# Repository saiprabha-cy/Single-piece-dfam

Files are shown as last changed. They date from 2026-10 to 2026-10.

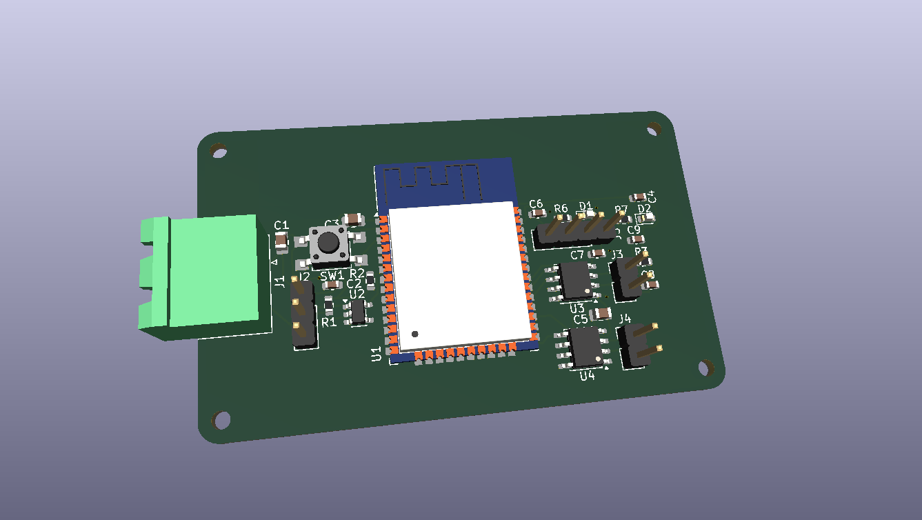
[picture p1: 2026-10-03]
04_kicad_board/sensor_board/sensor_board/sensor_board.png

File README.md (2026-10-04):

# Single-Piece DfAM Redesign of a Liquid Rocket Injector/Nozzle Assembly

A capstone project applying **Design for Additive Manufacturing (DfAM)**
principles to a small liquid rocket engine injector/nozzle assembly —
exploring how a traditionally multi-part, bolted engine assembly can be
redesigned as a single consolidated 3D-printed part.

## Motivation

Several modern small-launch-vehicle companies have moved toward 3D-printing
entire rocket engines as a single piece, eliminating the joints, fasteners,
and assembly steps of traditionally machined multi-part engines. This
project applies that same design philosophy at a smaller, student-accessible
scale: take a conventionally-designed multi-part injector/nozzle assembly,
redesign it as one consolidated additively-manufactured part, and validate
the redesign with both hand calculations and simulation.

## Project Stages

| Stage | Folder | Status |
|---|---|---|
| 1. Propulsion calculations | `01_calculations/` | ✅ Complete |
| 2. Baseline multi-part CAD | `02_cad/baseline_multipart/` | ✅ Complete |
| 3. Single-piece DfAM redesign | `02_cad/dfam_redesign/` | ✅ Complete |
| 4. Structural/thermal validation | `03_simulation/` | ✅ Structural complete; thermal documented as a known limitation |
| 5. Sensor/telemetry board | `04_kicad_board/` | ✅ Complete (0 DRC errors) |
| 6. Print-readiness analysis | `05_print_readiness/` | 🔜 Scoped as future work (see below) |
| 7. Final report | `06_report/` | ✅ Complete |

## Design Case (Assumed, Representative Values)

This project uses **representative values** for a generic small LOX/Kerosene
test-case engine, not any specific company's proprietary specifications.

- Target thrust: 3,000 N
- Chamber pressure: 20 bar
- Propellants: LOX / Kerosene (RP-1)
- Assumed sea-level Isp: 290 s

## Key Results

| Metric | Baseline (multi-part) | Redesign (single-piece) |
|---|---|---|
| Part count | 3 | 1 |
| Fastener interfaces | 2 (1 bolted, 1 rigid-joint only) | 0 |
| Mounting holes | 8 | 0 |
| Cooling provisions | None | 6 integrated channels |
| Structural safety factor (20 bar) | — | 6.24 (Ti-6Al-4V, SimScale) |

## Tools Used

- **Python** (SciPy) — propulsion calculations
- **Autodesk Fusion 360** (Personal Use license) — CAD modeling + built-in simulation
- **SimScale** — structural/thermal validation
- **KiCad** — sensor/telemetry PCB design

### Future Extensions
- **PrusaSlicer / Cura** — print-readiness and support-structure analysis
  (scoped as future work; see `05_print_readiness/`)
- Coolant inlet/outlet port routing on the DfAM redesign
- Full channel count (6 → 24) for production-representative coverage
- Chamber L* correction (increase straight-section length for realistic
  combustion residence time)

## Known Limitations

- **Chamber L\*** (characteristic length) is 263mm against a typical
  800-1500mm range for LOX/Kerosene engines — the as-modeled chamber is
  shorter than standard practice would recommend. This is a known,
  documented simplification; it does not affect the validity of the
  single-piece consolidation comparison, which is geometry-independent of
  chamber length. See `01_calculations/results/design_targets.json`.
- **Thermal simulation** was attempted in SimScale but diverged (likely due
  to an incomplete fluid-flow boundary definition in the initial CHT setup).
  Due to free-tier compute limits, a corrected re-run was not completed.
  The Stage 1 hand-calculated estimate (19.2 MW/m², target wall temp 800K)
  is retained as the primary thermal reference. See
  `03_simulation/validation_comparison.md`.
- **Cooling channel count** was reduced from a production-representative
  24 channels to 6, to keep the modeling scope achievable within the
  project timeline.
- **Print-readiness analysis** (slicer-based orientation/support check) was
  not completed; see Future Extensions above.

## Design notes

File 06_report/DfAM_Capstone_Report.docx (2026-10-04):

Single-Piece DfAM Redesign of a Liquid Rocket Injector/Nozzle Assembly

A Design-for-Additive-Manufacturing case study: propulsion calculations, baseline CAD, single-piece redesign, structural validation, and instrumentation design

# 1. Motivation

Several modern small-launch-vehicle companies have moved toward 3D-printing entire rocket engines as a single piece, eliminating the joints, fasteners, and assembly steps inherent to traditionally machined multi-part engines. This project applies that same design philosophy at a smaller, student-accessible scale: a conventionally-designed multi-part injector/nozzle assembly is redesigned as one consolidated additively-manufactured part, and the redesign is validated using hand calculations and simulation.

The project uses representative values for a generic small LOX/Kerosene test-case engine throughout — not any specific company's proprietary specifications.

# 2. Design Targets (Propulsion Calculations)

A Python script (SciPy) was used to derive design targets from a set of assumed operating parameters, representative of a small liquid engine test case.

## 2.1 Assumed Inputs

Parameter | Value
Target thrust | 3,000 N
Chamber pressure | 20 bar (2 MPa)
Propellants | LOX / Kerosene (RP-1)
Assumed sea-level Isp | 290 s
Oxidizer:fuel ratio | 2.5
Characteristic velocity (c*) | 1,750 m/s

## 2.2 Calculated Design Targets

Output | Value
Total propellant mass flow | 1.055 kg/s (0.753 ox + 0.301 fuel)
Injector pressure drop | 3.5 bar (17.5% of chamber pressure)
Oxidizer orifices | 49 × 1.0 mm
Fuel orifices | 24 × 1.0 mm
Throat diameter | 34.28 mm
Exit diameter | 64.97 mm
Exit Mach number | 2.54
Area ratio (Ae/At) | 3.59
Estimated heat flux (throat) | 19.2 MW/m²

## 2.3 Chamber Geometry Check

A characteristic-length (L*) and contraction-ratio check was run against the as-modeled baseline chamber dimensions (Ø55mm bore, 90mm straight length). This returned L* ≈ 263mm, against a typical LOX/Kerosene design range of 800–1500mm. This indicates the chamber, as modeled, is shorter than standard practice would recommend for complete combustion residence time. This is documented as a known limitation; it does not affect the validity of the single-piece consolidation comparison, which is geometry-independent of chamber length.

# 3. Baseline Design (Multi-Part)

The baseline assembly was modeled in Autodesk Fusion 360 (Personal Use license) as three separate components, representative of a traditionally-machined engine assembly:

- Injector plate — Ø70mm disk, 10mm thick, with 73 injector holes (49 oxidizer + 24 fuel) across 5 concentric rings (Ø12/18/24/30/36mm), plus an Ø82mm mounting flange with 8 ×4.5mm clearance holes on a Ø76mm bolt circle
- Combustion chamber — Ø55mm ID, Ø65mm OD, 90mm straight length, 5mm wall
- Nozzle — converging-diverging profile, Ø55mm inlet, Ø34.28mm throat, Ø64.97mm exit, 70mm axial length

The three components were assembled using two rigid joints (injector-to-chamber, chamber-to-nozzle). Only the injector-to-chamber interface includes a bolted flange (8 × M4 clearance holes); the chamber-to-nozzle interface is a positional joint only, without modeled fasteners — noted here as an acknowledged simplification of the baseline.

# 4. Single-Piece DfAM Redesign

The redesign consolidates all three baseline components into a single revolved solid body, modeled directly from the same throat/exit/injector dimensions as the baseline, ensuring a fair comparison.

## 4.1 Design Features

- One continuous revolved body from injector face through chamber, throat, and nozzle exit — no seams, flanges, or fasteners
- Same 73-hole injector pattern (49 oxidizer + 24 fuel), cut into a solid 10mm end cap
- 6 integrated cooling channels (1.5mm liner + 3mm channel height + 2.5mm outer skin), left open at both ends to allow powder removal in a metal powder-bed process and to double as coolant ports
- 1mm fillets at the two internal direction-change corners (chamber-to-throat, throat-to-nozzle) to reduce stress concentration

## 4.2 Part-Count Comparison

Metric | Baseline (multi-part) | Redesign (single-piece)
Part count | 3 | 1
Fastener interfaces | 2 (1 bolted, 1 joint-only) | 0
Mounting holes | 8 | 0
Cooling provisions | None | 6 integrated channels

Note: the cooling channel count (6) was reduced from a production-representative value (e.g. 24) to keep the modeling scope achievable within the project timeline; this is noted as a deliberate simplification.

# 5. Structural & Thermal Validation (SimScale)

## 5.1 Structural Simulation

A static structural simulation was run on the single-piece redesign under a 20 bar (2 MPa) internal pressure load, with the material assigned as Ti-6Al-4V (yield strength ≈ 880 MPa).

Result | Value
Maximum von Mises stress | 141 MPa
Material yield strength (Ti-6Al-4V) | 880 MPa
Safety factor | 6.24

A safety factor of 6.24 indicates the 7mm wall thickness is structurally conservative for the applied pressure load — comfortably exceeding typical aerospace practice (1.5–2.0×). This suggests a future iteration could explore wall-thickness reduction to trade some margin for mass savings.

## 5.2 Thermal Simulation — Documented Limitation

A steady-state thermal simulation was attempted to validate the Stage 1 hand-calculated heat flux estimate (19.2 MW/m², target wall temperature 800K). The initial setup (Conjugate Heat Transfer analysis) produced non-physical results (solver divergence, reporting temperatures from −1832K to 7.99×10⁵K), most likely due to an incomplete fluid-flow boundary definition inherent to the CHT analysis type — a simpler steady-state conduction analysis would have been the more appropriate choice for the boundary conditions defined.

Due to free-tier compute limits on the simulation platform, a corrected re-run was not completed within the project timeline. The Stage 1 first-order estimate is retained as the primary thermal reference for this project. This is reported transparently as a limitation rather than omitted, consistent with the project's overall approach of validating claims and documenting gaps honestly.

# 6. Sensor & Telemetry Board (KiCad)

A sensor/telemetry PCB was designed in KiCad to represent how the redesigned part could be instrumented during a hypothetical static test — directly applying an electronics/embedded-systems background to a propulsion hardware context.

## 6.1 Board Features

- ESP32 microcontroller module for sensor readout and data logging
- Chamber pressure sensor input (analog, with RC low-pass filtering)
- Two thermocouple amplifier inputs (SPI) for throat and injector temperature monitoring
- Onboard voltage regulation (barrel/terminal block input → 3.3V logic rail)
- Reset button, status LEDs, 4-corner mounting holes

The board passed design rule checks (DRC) with 0 errors. Schematic, PCB layout, Gerber/drill files, bill of materials, and a 3D render are included in the project repository.

# 7. Known Limitations & Future Work

- Chamber L* (263mm vs. a typical 800–1500mm range) — the as-modeled chamber is shorter than standard LOX/Kerosene practice would recommend; does not affect the validity of the part-count/consolidation comparison
- Thermal simulation incomplete — documented above; a corrected steady-state conduction run is the logical next step
- Cooling channel count reduced to 6 from a production-representative value for modeling-scope reasons
- Coolant inlet/outlet port routing was not modeled
- Print-readiness analysis (slicer-based orientation and support-structure check) was scoped as future work. The part would realistically be manufactured via metal powder-bed fusion rather than FDM; a slicer tool approximates general printability concepts (overhangs, orientation) but does not simulate the actual metal additive manufacturing process

# 8. Conclusion

This project demonstrates the practical reasoning behind single-piece additive manufacturing for rocket engine hardware: a 3-part, 8-fastener baseline assembly was redesigned as a single consolidated body with zero fasteners and integrated cooling — while remaining dimensionally consistent with hand-calculated propulsion design targets and passing a structural validation check with significant margin (SF = 6.24). Equally important, every limitation encountered along the way — the short chamber L*, the diverged thermal simulation, the reduced channel count — was investigated, understood, and documented rather than hidden, reflecting an engineering approach grounded in validating claims rather than assuming them.

Tools used: Python (SciPy) for propulsion calculations; Autodesk Fusion 360 for CAD modeling and built-in simulation; SimScale for structural and thermal validation; and KiCad for sensor/telemetry PCB design.

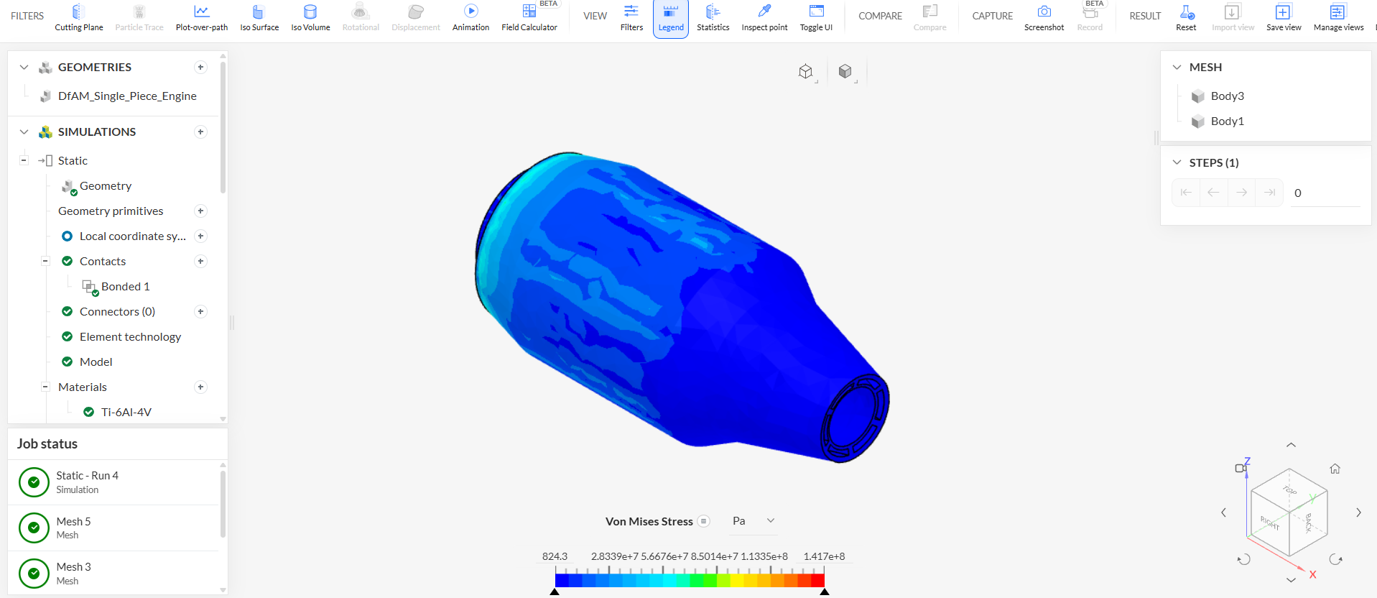
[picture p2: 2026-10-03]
03_simulation/exports/structural_stress_contour.png

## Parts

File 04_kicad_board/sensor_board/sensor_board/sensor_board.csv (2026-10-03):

Id | Designator | Footprint | Quantity | Designation | Supplier and ref
1 | C1 | C_0805_2012Metric | 1 | 10 µF, 10 V
2 | C2 | C_0603_1608Metric | 1 | 100 nF, 10 V
3 | C3 | C_0805_2012Metric | 1 | 10 µF, 6.3 V
4 | C4, C6 | C_0603_1608Metric | 2 | 100 nF
5 | C5 | C_0805_2012Metric | 1 | 10 µF
6 | C7, C8, C9 | C_0603_1608Metric | 3 | 100nF
7 | D1, D2 | LED_0603_1608Metric | 2 | LED
8 | J1 | PhoenixContact_MSTBA_2,5_2-G_1x02_P5.00mm_Horizontal | 1 | POWER IN
9 | J2 | PinHeader_1x03_P2.54mm_Vertical | 1 | PRESSURE
10 | J3 | PinHeader_1x02_P2.54mm_Vertical | 1 | THERMOCOUPLE 1
11 | J4 | PinHeader_1x02_P2.54mm_Vertical | 1 | THERMOCOUPLE 2
12 | J5 | PinHeader_1x04_P2.54mm_Vertical | 1 | UART
13 | R1, R6, R7 | R_0603_1608Metric | 3 | 1k
14 | R2 | R_0603_1608Metric | 1 | 10k
15 | R3 | R_0603_1608Metric | 1 | 20k
16 | SW1 | SW_SPST_TL3305A | 1 | RESET
17 | U1 | ESP32-WROOM-32 | 1 | ESP32-WROOM-32E
18 | U2 | SOT-23-5 | 1 | AP2112K-3.3
19 | U3, U4 | SOIC-8_3.9x4.9mm_P1.27mm | 2 | MAX31855EASA

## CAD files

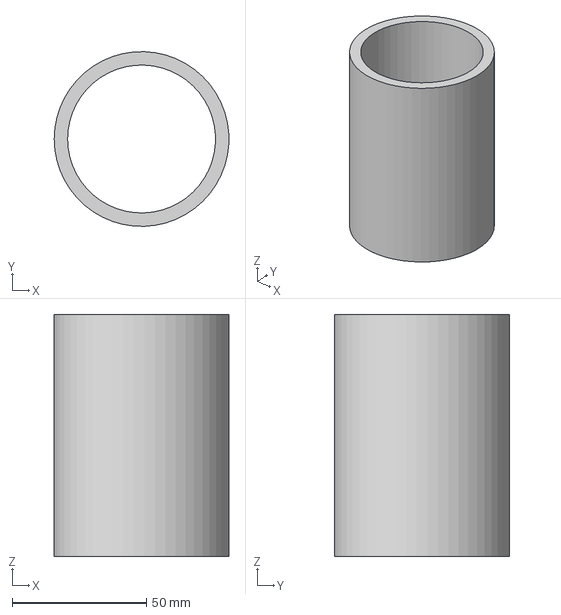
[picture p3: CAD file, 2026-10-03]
02_cad/baseline_multipart/STEP_Exports/Combustion_Chamber.step
64.9 x 65.0 x 90.0 mm

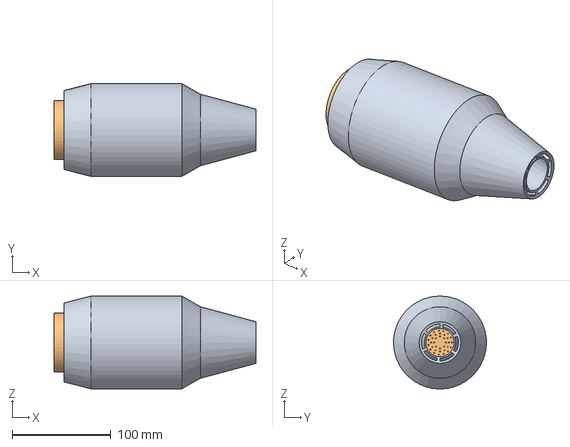
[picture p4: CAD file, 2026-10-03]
02_cad/dfam_redesign/STEP_Exports/DfAM_Single_Piece_Engine.step
204.3 x 94.0 x 93.9 mm

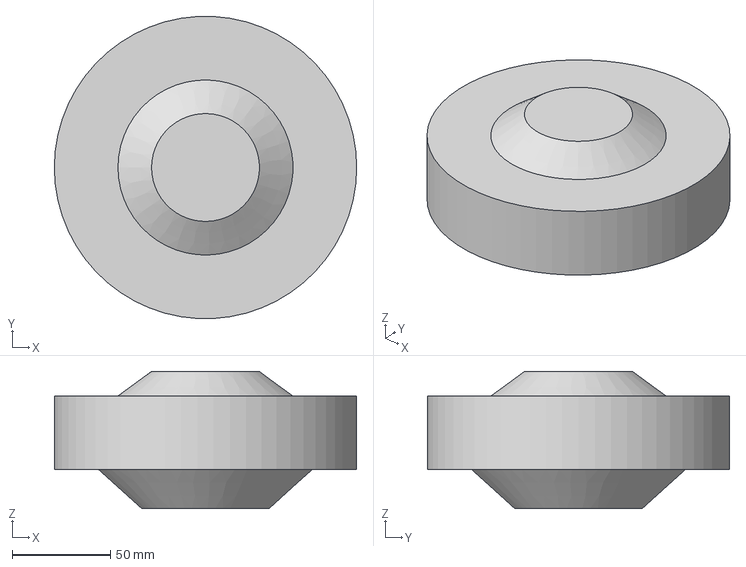
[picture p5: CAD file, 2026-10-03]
02_cad/baseline_multipart/STEP_Exports/Nozzle.step
154.2 x 154.0 x 70.0 mm

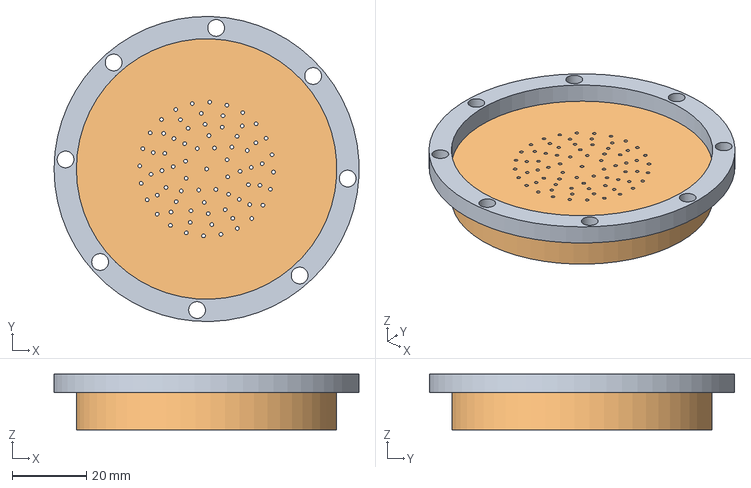
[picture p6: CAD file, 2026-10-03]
02_cad/baseline_multipart/STEP_Exports/Injector_Plate.step
81.9 x 82.0 x 15.0 mm

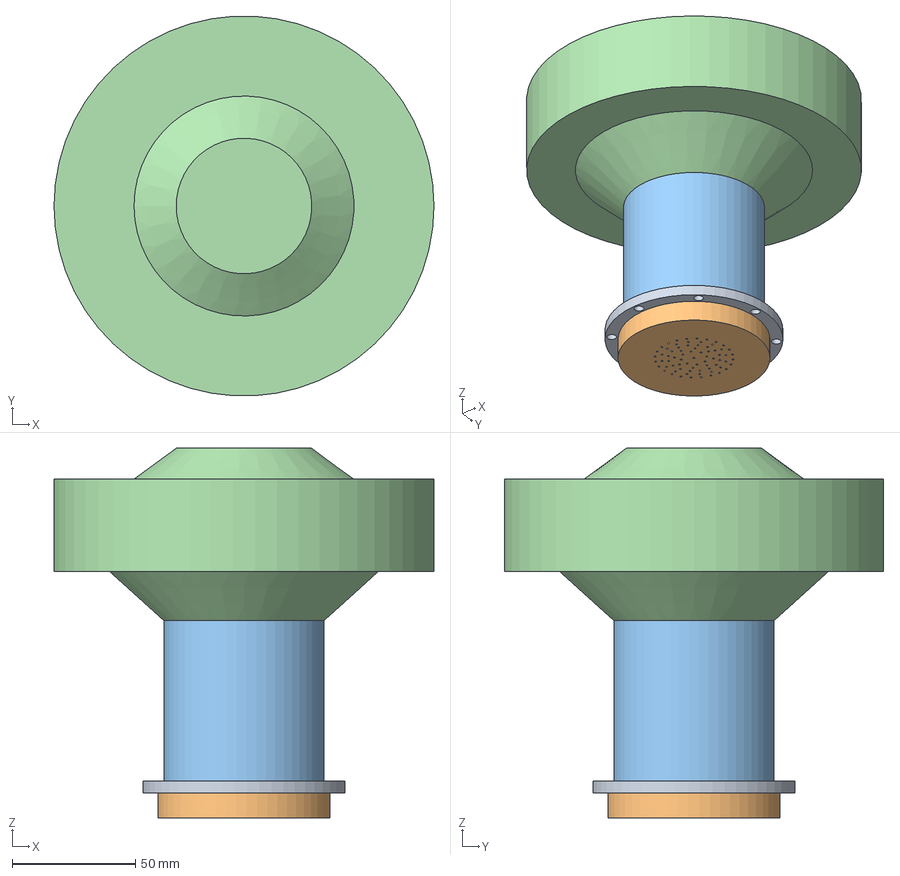
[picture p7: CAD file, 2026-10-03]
02_cad/baseline_multipart/STEP_Exports/Baseline_Injector_Plate.step
154.2 x 154.0 x 150.0 mm

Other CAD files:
05_print_readiness/DfAM_Single_Piece_Engine.stl

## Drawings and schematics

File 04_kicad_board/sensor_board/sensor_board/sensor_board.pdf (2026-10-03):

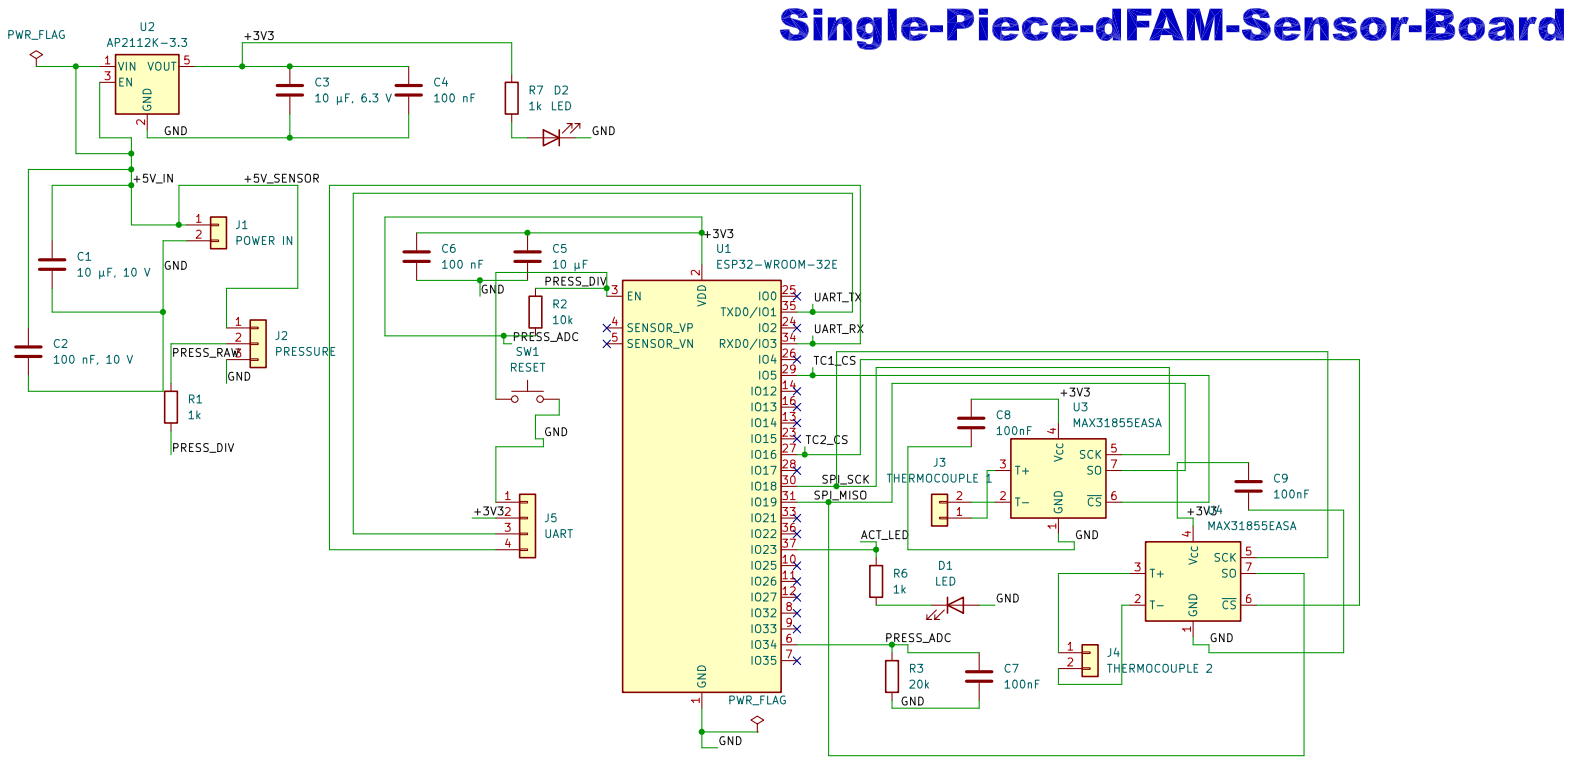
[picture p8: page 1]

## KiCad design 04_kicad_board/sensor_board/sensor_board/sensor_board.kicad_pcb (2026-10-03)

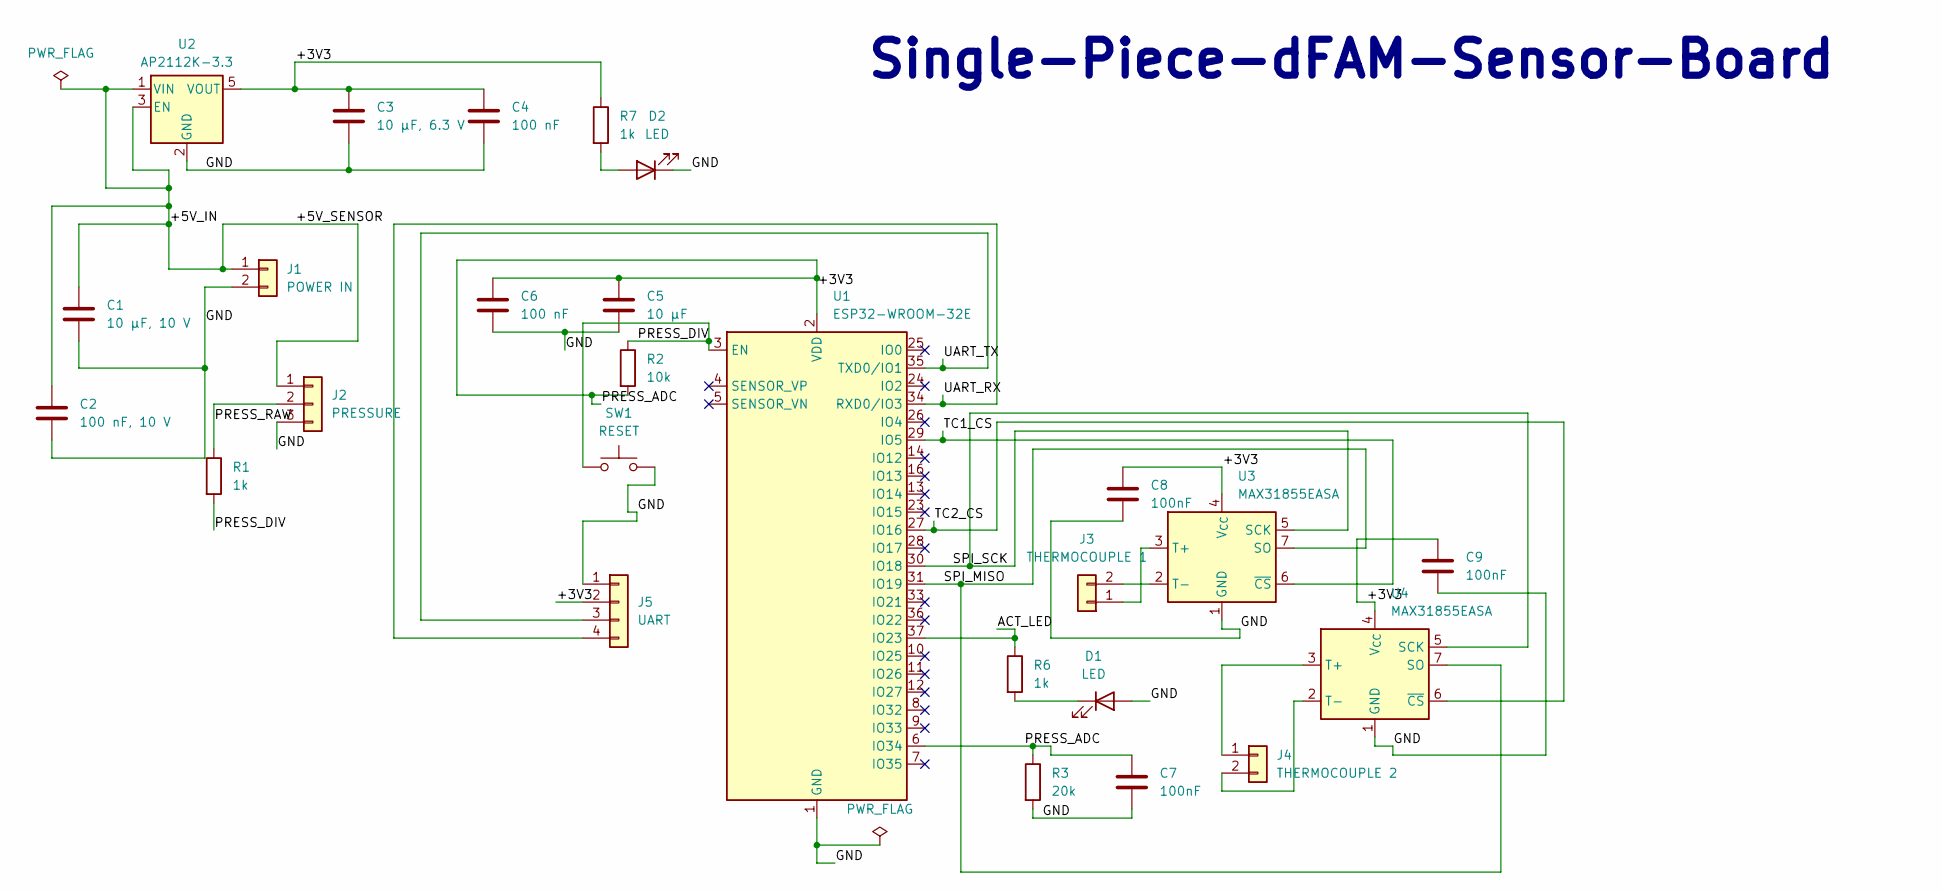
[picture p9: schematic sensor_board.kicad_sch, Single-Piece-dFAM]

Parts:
C1: 10 µF, 10 V; C_0805_2012Metric
C2: 100 nF, 10 V; C_0603_1608Metric
C3: 10 µF, 6.3 V; C_0805_2012Metric
C4, C6: 100 nF; C_0603_1608Metric
C5: 10 µF; C_0805_2012Metric
C7, C8, C9: 100nF; C_0603_1608Metric
D1, D2: LED; LED_0603_1608Metric
J1: POWER IN; PhoenixContact_MSTBA_2,5_2-G_1x02_P5.00mm_Horizontal
J2: PRESSURE; PinHeader_1x03_P2.54mm_Vertical
J3: THERMOCOUPLE 1; PinHeader_1x02_P2.54mm_Vertical
J4: THERMOCOUPLE 2; PinHeader_1x02_P2.54mm_Vertical
J5: UART; PinHeader_1x04_P2.54mm_Vertical
R1, R6, R7: 1k; R_0603_1608Metric
R2: 10k; R_0603_1608Metric
R3: 20k; R_0603_1608Metric
SW1: RESET; SW_SPST_TL3305A
U1: ESP32-WROOM-32E; ESP32-WROOM-32
U2: AP2112K-3.3; SOT-23-5
U3, U4: MAX31855EASA; SOIC-8_3.9x4.9mm_P1.27mm

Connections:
/+3V3: C3.1, C4.1, C5.1, C6.1, C7.1, C8.1, C9.1, J5.2, R2.2, R3.1, R7.1, U1.2 (VDD), U1.6 (IO34), U2.5 (VOUT), U3.4 (V_{CC}), U4.4 (V_{CC})
/+5V_IN: C1.1, C2.1, J1.1, J2.1, U2.1 (VIN), U2.3 (EN)
/ACT_LED: R6.1, U1.37 (IO23)
/GND: C1.2, C2.2, C3.2, C4.2, C5.2, C6.2, C7.2, C8.2, C9.2, D1.2 (A), D2.1 (K), J1.2, J2.3, J5.1, R3.2, SW1.2, U1.1 (GND), U1.15 (GND), U1.38 (GND), U1.39 (GND), U2.2 (GND), U3.1 (GND), U4.1 (GND)
/PRESS_DIV: R1.2, R2.1, SW1.1, U1.3 (EN)
/PRESS_RAW: J2.2, R1.1
/SPI_MISO: U1.31 (IO19), U3.7 (SO), U4.7 (SO)
/SPI_SCK: U1.30 (IO18), U3.5 (SCK), U4.5 (SCK)
/TC1_CS: U1.29 (IO5), U3.6 (~CS)
/TC2_CS: U1.27 (IO16), U4.6 (~CS)
/UART_RX: J5.4, U1.34 (RXD0/IO3)
/UART_TX: J5.3, U1.35 (TXD0/IO1)
unnamed: D1.1 (K), R6.2
unnamed: D2.2 (A), R7.2
unnamed: J3.1, U3.3 (T+)
unnamed: J3.2, U3.2 (T-)
unnamed: J4.1, U4.3 (T+)
unnamed: J4.2, U4.2 (T-)

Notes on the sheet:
Single-Piece-dFAM-Sensor-Board

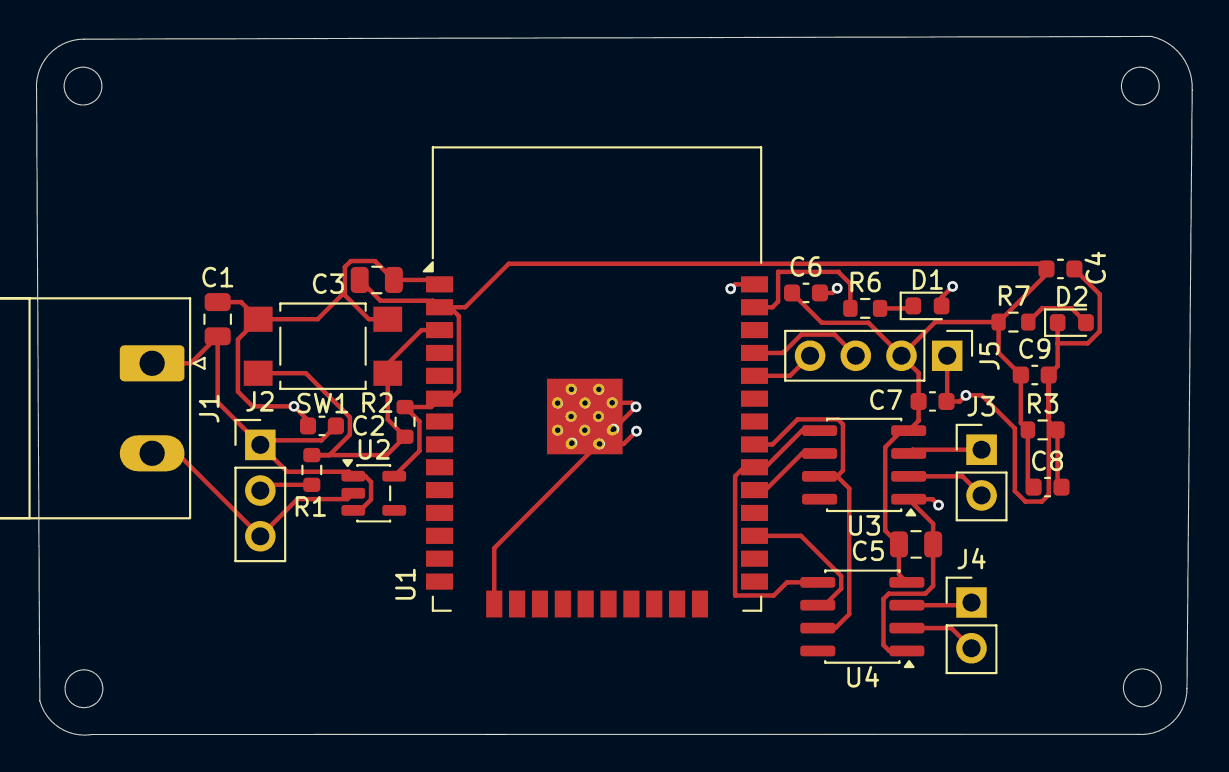
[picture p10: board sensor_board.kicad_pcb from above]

Board: 2 copper layers, 64.2 x 38.8 mm, 26 parts (0 on the bottom side), 18 nets.

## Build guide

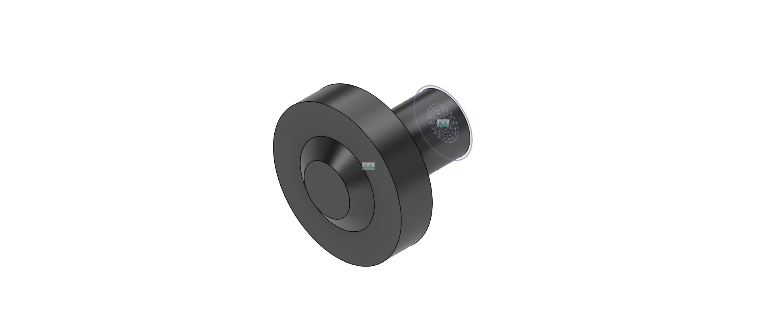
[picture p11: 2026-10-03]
02_cad/baseline_multipart/STEP_Exports/Baseline_Injector_Plate1.png

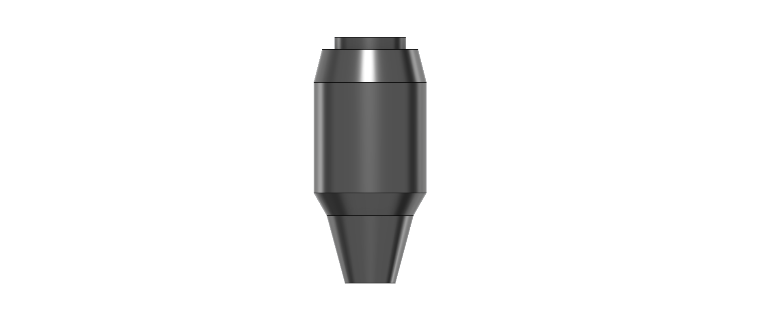
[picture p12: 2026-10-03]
02_cad/dfam_redesign/STEP_Exports/DfAM_Single_Piece_Engine-3.png

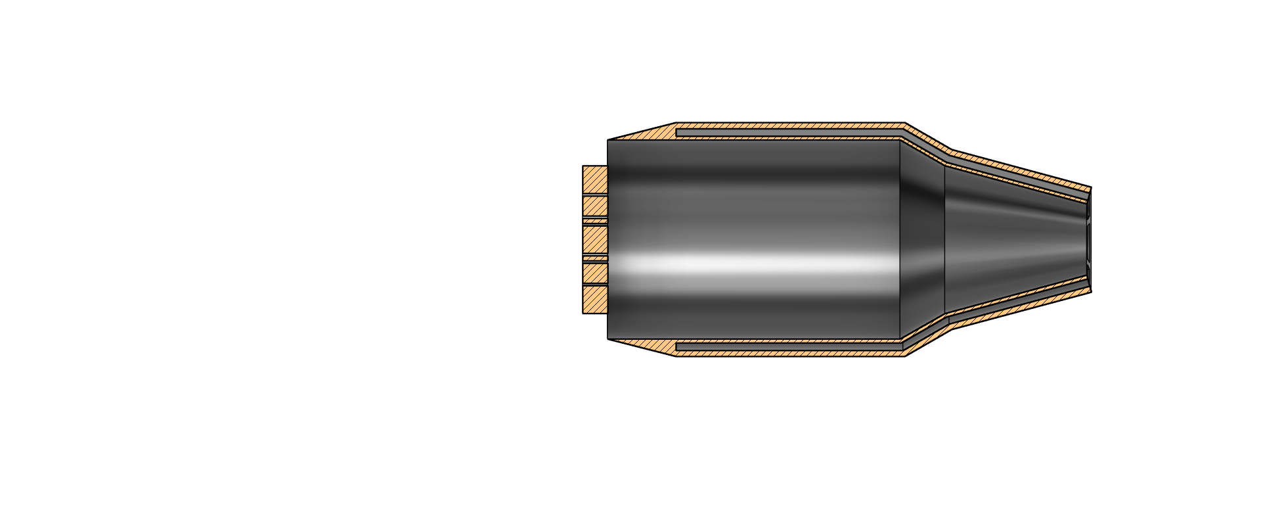
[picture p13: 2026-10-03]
02_cad/dfam_redesign/STEP_Exports/DfAM_Single_Piece_Engine-2.png

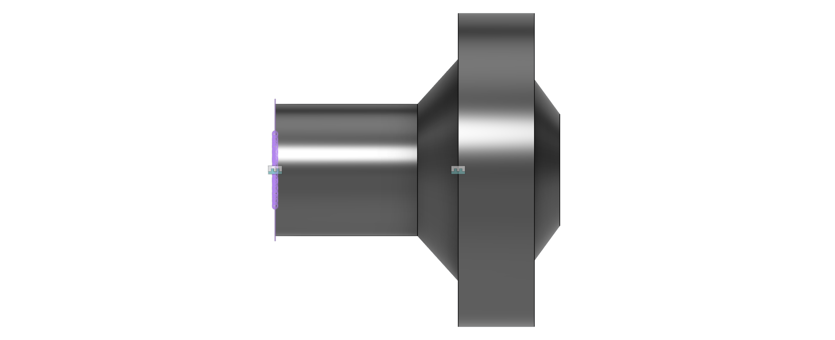
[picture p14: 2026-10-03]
02_cad/baseline_multipart/STEP_Exports/Baseline_Injector_Plate.png

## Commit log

2026-10-03 Stage 5: KiCad sensor/telemetry board complete
    [Baseline_Injector_Plate.step, Combustion_Chamber.step, DfAM_Single_Piece_Engine.step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]
2026-10-04 full documentation completed
    [DfAM_Single_Piece_Engine.stl]
